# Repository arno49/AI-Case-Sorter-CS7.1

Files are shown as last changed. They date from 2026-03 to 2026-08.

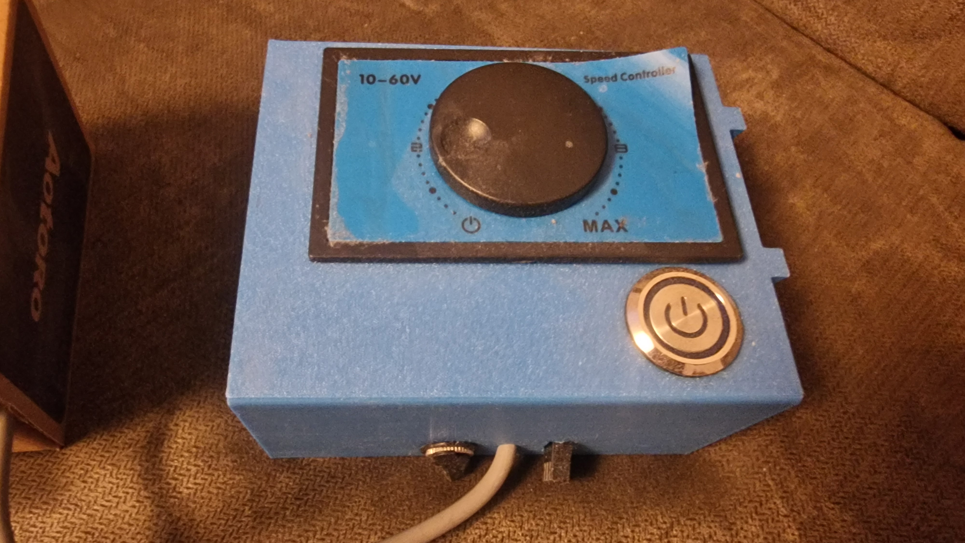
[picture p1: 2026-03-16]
CommunityContributions/Misc/SilverBullit/20260315_165633006.jpg

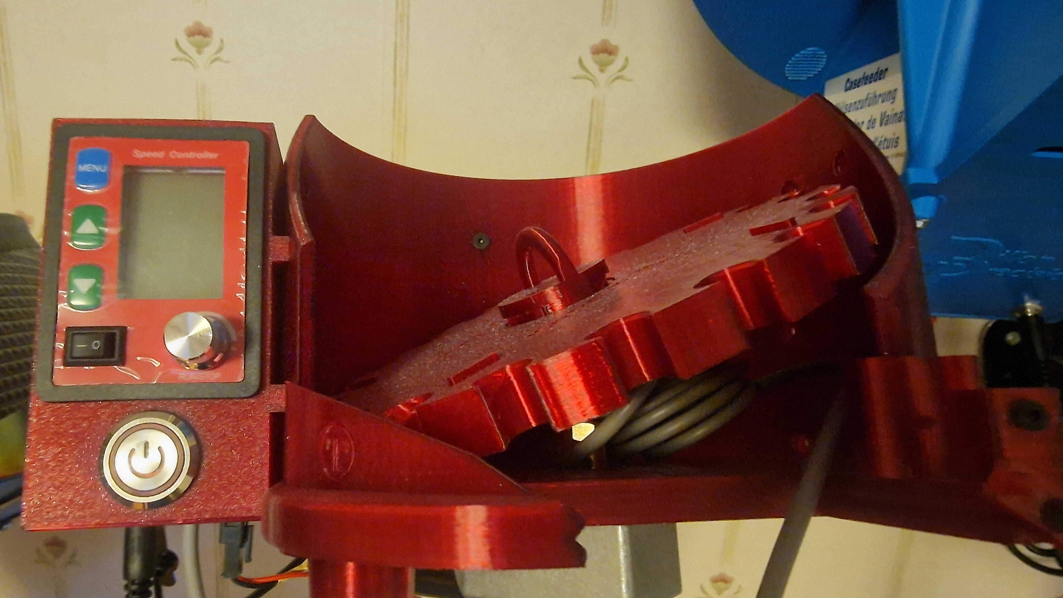
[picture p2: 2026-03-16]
CommunityContributions/Misc/SilverBullit/20260315_165454001.jpg

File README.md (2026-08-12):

# AI-Case-Sorter-CS7.1

This project builds a case sorter that uses machine vision and machine learning
to identify cartridge cases by headstamp. The repository contains the canonical
Arduino firmware, host protocol tooling, mechanical models, and the approved
architecture for a future Raspberry Pi 5 control appliance.

## Current software status

The canonical firmware is `7.1.260714.6`. Reset and the default `uno` build
remain protocol v1 for compatibility; `uno_v2` compiles opt-in v2 support while
also starting in v1.

| Environment | Current validated result |
| --- | --- |
| `uno` | 17,594 bytes flash / 899 bytes static SRAM |
| `uno_v2` | 26,290 bytes flash / 997 bytes static SRAM |
| `native` | 89 tests pass |
| `native_v2` | 49 tests pass |
| Python host package | 116 pytest tests pass |
| Python daemon/simulator | 318 pytest tests pass |
| `cs71-vision` package | 73 pytest tests pass |

The Python package under `host/` implements the v1/v2 client, typed protocol
models, CRC, fail-closed recovery, and the `cs71-protocol` compatibility CLI.
Physical bench, Linux DTR, HIL, and Windows-application qualification remain
required; software tests do not satisfy those gates. See
[ArduinoCode/README.md](ArduinoCode/README.md) for firmware details and
[host/README.md](host/README.md) for the host API and CLI.

## Software checks

From the repository root, run the firmware environments and the no-hardware host
package checks:

```sh
pio run -e uno && pio run -e uno_v2
pio test -e native && pio test -e native_v2
(cd host && python -m pip install ".[dev]" "build==1.2.2.post1" && python -m pytest && python -m build --wheel --sdist)
python -m unittest discover -s appliance/contracts/tests -v
(python -m pip install --require-hashes -r appliance/daemon/requirements-dev.txt && python -m pip install --no-build-isolation -e ./host -e ./appliance/daemon && cd appliance/daemon && ruff format --check . && ruff check . && mypy && pytest && python -m build --no-isolation --wheel --sdist)
(cd appliance/web && npm ci && npm run check:api && npm run lint && npm run check && npm test && npm run build)
python -m unittest discover -s appliance/ops/tests -v
```

These checks do not replace firmware serial parity, HIL, or Windows
qualification. `appliance/ops/tests/smoke-test.sh` is a further, functional
check that needs root on a real Linux host — it runs in CI (the
`appliance-ops` job) but is not part of this no-hardware list, and it does
not run on a Raspberry Pi either.

## Raspberry Pi 5 appliance documentation

The Raspberry Pi 5 control appliance executive summary is
[RASPBERRY_PI_WEB_ARCHITECTURE.md](RASPBERRY_PI_WEB_ARCHITECTURE.md). Its canonical
architecture, ADRs, delivery backlog, roadmap, and traceability are under
[docs/architecture/](docs/architecture/README.md). Firmware protocol behavior remains
in [ArduinoCode/PROTOCOL_V2.md](ArduinoCode/PROTOCOL_V2.md); the Python host-library
boundary is documented in [host/README.md](host/README.md).

The appliance architecture and executable private
[`cs71d` OpenAPI v1 contract](appliance/contracts/cs71d-v1.openapi.json) are
approved, and initial Python daemon/SvelteKit SSR workspaces now exist under
`appliance/`. The daemon workspace includes a deterministic, explicit-clock
protocol simulator for software-only development, and a single-owner serial
worker that confines all controller I/O to one dedicated thread and publishes
its session state. Opening a real serial port on Linux stays blocked by the
unqualified DTR gate. The web workspace now authenticates local operators: its
own `web.db`, Argon2id password hashing, opaque server-side sessions behind a
deny-by-default request hook, and one-time expiry-bound bootstrap provisioning
instead of a default password. Roles are enforced server-side against the
documented capability matrix, with every route declaring what it requires, and
state-changing requests must pass an origin and CSRF check and stay inside
documented rate, concurrency and size budgets. A socket-only daemon client backs
a dashboard that reads the machine snapshot and submits the software stop,
recording every attempt in the web audit. The dashboard also watches the machine
live: one reader of the daemon's event stream is fanned out to every open
browser, and a browser that may have missed something re-reads a snapshot rather
than presenting a state assembled from a gap. What the dashboard says is decided
in one tested module: acceptance is never worded as completion, a terminal the
controller did not confirm reads as an outcome that is not known, an unobserved
axis reads "not known" rather than "not homed", and the software stop — still
not an emergency stop — is the first control a keyboard reaches. Manual
connect, home and sort controls are offered capability-driven from the snapshot
the operator is looking at, each command form carrying that snapshot's
generation and a fresh idempotency key so a stale page is refused and a
resubmission cannot move the machine twice; the feed control stays disabled
with the daemon's reason for the unqualified firmware gate shown verbatim. The
operation history screen reads the durable record the daemon keeps, filtered
by exactly the state and type values the contract defines and paged forward
on the daemon's own cursor, describing every row with the same wording the
dashboard uses so an unsettled operation is never worded as a completion. A
machine whose state is not known renders visibly distinct from ordinary
attention rather than as a shade of it. Recovery is a dashboard control
gated to administrators, requiring an explicit confirmation checkbox this
workspace checks before anything reaches the daemon. A system view shows
firmware version, journal health inferred from recorded faults, storage
health explicitly reported as not available, and DTR-gate status read from
the daemon — presented as the project's own evidence-status legend defines
it and never as a pass. `appliance/ops/install.sh` installs both services as
separate least-privilege systemd units, a udev rule keyed to a specific
adapter's vendor ID, product ID and serial number together, and a Caddy site
that proxies only to loopback SvelteKit; its own smoke test proves the real
sandbox for real on a Linux CI host, though not yet on a Raspberry Pi.
`appliance/ops/backup.sh`, `restore.sh` and `upgrade.sh` take a
SQLite-consistent, checksummed backup of both databases and configuration on
a daily timer; restore verifies that checksum and each database's integrity
before installing anything and proves the daemon and web service actually
answer afterward; upgrade rebuilds from the checkout and rolls artifacts and
data back through restore on any failure before the web service is confirmed
healthy. The daemon's production profile now blocks new work the same way a
failed journal write already does when free disk space runs low or its own
backup has not succeeded recently enough. A third appliance service,
`cs71-vision` ([ADR-0013](docs/architecture/adr/0013-vision-classifier-service-and-hybrid-autonomy.md)),
now exists: a camera capture abstraction, packaged the same least-privilege
way, with a deterministic fixture backend for development/CI and a real
V4L2 backend for production that is not yet evidenced against real camera
hardware; and a self-labeling dataset that asks the daemon which slot each
completed sort actually reached and pairs that with the frame captured
nearest it, storing a labeled example only once the daemon has confirmed
the outcome — never guessed at from a frame alone.

The canonical firmware uses cooperative proximity settling: after the feed
sensor has been inactive longer than its debounce timeout, brass must keep the
sensor continuously active for the configured settle time. A sensor drop
cancels and restarts the full interval; brass already active at boot does not
settle until a qualifying absence occurs.

Sorter pre-homing jogs and the 40 ms `sorttest:` pacing interval are also
cooperative. Serial commands, including `stop`, remain responsive between
sorter steps and diagnostic moves. Runtime code uses no millisecond `delay()`;
only the microsecond delays that form and pace individual step pulses remain.

The `test:` and `sorttest:` diagnostics use the independent
`SORTER_SLOT_COUNT` setting (default 8), selecting slots from 0 through 7 by
default. It can be changed for the current session with the exact serial command
`slotcount:{count}`; see [ArduinoCode/README.md](ArduinoCode/README.md) for
limits and application compatibility details.

## Instructions
Most of the information you need to build this project is available in [Instructions.pdf](Instructions.pdf).

---------
## Parts List
The parts list for this project can be found here:
[Parts List](https://www.reloadingrecipes.com/HeadstampSorter/Partslist)

--------

# CS7.1 Video Build Series

The release video for this project is here:

Watch the video (https://youtu.be/s7dy0odA44U)

Follow along with me as I build the various components of this system. 

## Classifier
Build the Classifier (https://youtu.be/lhxDmvg5AVQ)

## Sorter
Build the Sorter (https://youtu.be/rP7bBV_uqF4)

## Camera Module
Build the Camera (https://youtu.be/iOc7inAcXpQ)

## Electronics
Build the Electronics (https://youtu.be/cS54LOCpNGc)

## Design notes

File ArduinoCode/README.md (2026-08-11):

# AI-Case-Sorter-CS7.1
This repo was created to isolate all the code and resources for the CS7.1 Version

## Release validation status

Firmware `7.1.260714.6` compiles for Arduino Uno with PlatformIO. The current
software baseline has 89 passing `native` tests, 49 passing `native_v2` tests,
and 100 passing Python host tests. CI builds both Uno variants and runs the
firmware and host suites. Physical bench validation is still required before
treating this firmware as a hardware release: motor direction, homing and
offsets, stop latency, AirDrop pulse timing, PWM output, sensor behavior, Linux
DTR behavior, and Windows application compatibility have not been exercised
from the development environment.

### V2-08 software evidence

| Build | Flash | Static SRAM | Gate |
| --- | ---: | ---: | --- |
| `uno` | 17,594 bytes | 899 bytes | 29,000 / 1,250 bytes |
| `uno_v2` | 26,290 bytes | 997 bytes | 29,000 / 1,250 bytes |

The matching native resource fixture is
`test/support/v2_08_resource_fixture.h`. V2-08H hardware status is
**NOT_EXECUTED**: no hardware stand was used, so physical completion timing,
motor behavior, and cancellation timing remain unverified.

## Build and test

The canonical sketch remains
`ArduinoCode/CS71_Arduino/CS71_Arduino.ino`. Open it in Arduino IDE, select
**Arduino Uno**, and use **Verify** or **Upload**.

PlatformIO provides an optional command-line workflow from the repository root:

```sh
pio run -e uno
pio test -e native
```

Run the complete firmware and host software checks from the repository root:

```sh
pio run -e uno && pio run -e uno_v2
pio test -e native && pio test -e native_v2
(cd host && python -m pip install ".[dev]" "build==1.2.2.post1" && python -m pytest && python -m build --wheel --sdist)
```

Run one native test suite with:

```sh
pio test -e native -f test_logic
pio test -e native -f test_command_parser
pio test -e native -f test_machine_state
pio test -e native -f test_runtime_timer
pio test -e native -f test_feed_completion
pio test -e native -f test_proximity_settler
pio test -e native -f test_step_sequence
pio test -e native -f test_crc16
pio test -e native_v2 -f test_protocol_v2_envelope
pio test -e native_v2 -f test_physical_request_tracker
```

## Serial command framing

For the normative engineering contract used to build host applications, see
[`PROTOCOL.md`](PROTOCOL.md).

The approved opt-in protocol v2 and legacy compatibility switcher are specified
in [`PROTOCOL_V2.md`](PROTOCOL_V2.md). Its dependency-ordered implementation and
rollout plan is in [`PROTOCOL_V2_PLAN.md`](PROTOCOL_V2_PLAN.md).

The firmware accepts commands at 9600 baud. Each command is terminated by
newline (`\n`); a single carriage return immediately before newline is ignored,
so CRLF is also accepted. Command payloads may contain up to 40 bytes.

If a payload exceeds 40 bytes, the complete line is discarded through its
newline and the firmware replies `error:command too long`. The next line starts
a fresh command. Runtime setting values must be complete integers within their
supported ranges. Boolean settings accept `true`/`false` (case-insensitive) or
`1`/`0`; malformed values return `error:invalid <setting>` without changing the
previous value.

`slotcount:{count}` sets the number of destinations used by both diagnostic
commands and replies `ok`. The value must be at least 1 and no greater than
`floor(32767 / (SortSteps * SORT_MICROSTEPS)) + 1`; invalid input replies
`error:invalid slotcount` and preserves the previous value. Changing
`sortsteps:` is also rejected when it would make the current diagnostic slot
count unsafe. Slot count does not limit ordinary numeric, `xf:`, or `sortto:`
commands, whose existing AVR-safe range is unchanged.

`SlotCount` is deliberately absent from `getconfig`: supported Windows
application versions have not been verified to tolerate an additional JSON
property. Set it manually in a 9600-baud serial terminal with, for example,
`slotcount:8`, or send that exact command from the application's advanced
configuration facility after its usual `sortsteps:` initialization. Runtime
settings reset at restart. To change the firmware default, edit
`SORTER_SLOT_COUNT` in the user configuration section.

Frames containing an embedded NUL byte are discarded with
`error:invalid command`.

## Serial command reference

| Command | Response and behavior |
| --- | --- |
| `{slot}` | Queues a destination and starts the pipelined feed/sort cycle; eventually emits `done`. |
| `xf:{slot}` | Same cycle while bypassing the feed sensor; eventually emits `done`. |
| `sortto:{slot}` | Acknowledges with `ok` and moves directly for diagnostics. |
| `homefeeder`, `homesorter` | Acknowledge with `ok` when recovery starts. |
| `stop` | Cancels active work, disables the shared driver, and emits `stopped`. |
| `test:{count}`, `sorttest:{count}` | Emit `testing started`, progress lines, and run the requested diagnostics. |
| `version` | Emits the firmware version alone. |
| `getconfig` | Emits one line of JSON containing the supported runtime settings. |
| `ping` | Emits the legacy response ` ok` with a leading space. |

Runtime setters acknowledge valid values with `ok` and use these exact names:
`feedspeed:`, `feedsteps:`, `feedhomingoffset:`, `sortspeed:`, `sortsteps:`,
`sorthomingoffset:`, `slotcount:`, `notificationdelay:`, `slotdropdelay:`,
`automotorstandbytimeout:`, `debounceTimeout:`, `debounceTime:`,
`airdropenabled:`, `airdroppredelay:`, `airdroppostdelay:`,
`airdropdsignalduration:`, and `cameraledlevel:`. Preserve the mixed-case
debounce names and the legacy extra `d` in `airdropdsignalduration:`.

Unknown nonnumeric commands retain the legacy `ok` response. Invalid setters
emit `error:invalid <setting>`; framing errors, busy state, unavailable position,
and feed overtravel use their documented `error:` responses.

## Stop and recovery

`stop` is a software control command, not a certified emergency stop or a
substitute for physically isolating motor power. A complete exact `stop` frame
is handled while feed, sort, or homing motion is active and replies exactly:

```text
stopped
```

It disables the shared motor driver, forces the feed-done output low, cancels
motion, homing, tests, completion notifications, and the pending command, and
marks both axis positions unknown. Serial input is checked on each cooperative
loop pass, including between pre-homing sorter jog steps and sorter diagnostic
moves.

The machine starts in `Recovering` mode and enters `Running` only after both
axes finish homing, including configured offsets. After `stop`, issue
`homefeeder` and `homesorter` (in either order); each replies `ok` when homing
starts. The motor driver is re-enabled for recovery. Once both axes are known,
the sorter queue is reset to zero and normal commands are accepted. Builds with
either homing sensor disabled mark that axis known deterministically when its
home operation is serviced.

The startup sorter pre-jog runs as one step per loop pass. Feeder and sorter
homing begin together only after that jog completes, preserving startup
ordering without blocking serial input. `homesorter` acknowledges immediately,
runs the same cooperative pre-jog, and then homes only the sorter. Stop and
feed faults cancel a pending jog so it cannot later start homing.

While stopped or recovering, `stop`, `version`, `getconfig`, `ping`, all runtime
configuration setters, `homefeeder`, and `homesorter` remain available. Numeric
feed/sort commands, `xf:`, `sortto:`, `test:`, and `sorttest:` reply:

```text
error:not homed
```

While execution is busy, one complete ordinary command can be held pending.
Any additional completed ordinary frame replies `error:busy`; it starts a new
frame and is never appended to the pending command. A pending command is not
dispatched until motion and homing are idle and any preceding feed-cycle
`done` notification has been emitted.

## Nonblocking feed completion

After feed homing completes, feed notification runs cooperatively without
`delay()`. With AirDrop enabled, firmware waits `AirDropPreDelay`, drives
`FEED_DONE_SIGNAL` high for `AirDropSignalTime`, drives it low, waits
`NotificationDelay`, and then emits `done`. Without AirDrop, it waits only
`NotificationDelay`. AirDrop mode and all three durations are snapshotted when
completion starts, so a queued runtime setter affects the next cycle.

Completion remains busy until `done` is emitted, preserving one-command pending
behavior. `stop`, feed overtravel, or leaving `Running` mode cancels the
completion, forces `FEED_DONE_SIGNAL` low, and suppresses stale `done` output.
`AirDropPostDelay` remains the independent slot/drop clearance gate.

## Cooperative sorter diagnostics

`sorttest:` uses a cooperative 40 ms `RuntimeTimer` gate before each random
sorter move. Both `test:` and `sorttest:` choose from the upper-exclusive range
`[0, slotCount)`. The independent default of 8 covers slots 0–7; this expands
the former `test:` default range of 0–5. Chute spacing and slot count must both
match the installed mechanics and are not derived from each other. The
return-to-zero move and pending-command blocking are unchanged. `stop` cancels
the pacing gate and test. Runtime firmware contains no `delay()` calls; only
`delayMicroseconds()` calls for step pulse width and motor speed remain.

## Proximity settling

After the feed sensor has remained inactive for longer than
`DebounceTimeout`, the next detected case must keep the sensor continuously
active for `DebouncePauseTime` before feeding can begin. This settling interval
is cooperative, so serial handling and `stop` remain responsive. If the sensor
drops inactive during settling, the timer is canceled and a full active
interval is required when the case returns. A case already active at boot does
not settle until a qualifying absence occurs.

`xf:` and builds with `FEEDSENSOR_ENABLED=false` bypass readiness without
clearing a pending settle requirement. Stop and feed-fault/recovery paths reset
active settling so stale expiry cannot start movement.

A feed-overtravel fault disables the motor driver and marks the feeder position
unknown. An already accepted pending command is processed afterward under the
normal recovery restrictions, so movement receives `error:not homed` while
diagnostics and homing remain available. Home the feeder successfully before
movement commands are accepted again. If sorter motion was active when the
fault occurred, it is cancelled and the sorter must also be homed.

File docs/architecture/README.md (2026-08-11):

# CS7.1 Raspberry Pi 5 Architecture

**Status:** Proposed implementation architecture; decisions listed below are accepted. This set is the canonical architecture for the Raspberry Pi 5 control appliance. It supersedes detailed design material in [RASPBERRY_PI_WEB_ARCHITECTURE.md](../../RASPBERRY_PI_WEB_ARCHITECTURE.md), which is now an executive summary. Firmware wire behavior remains canonical in [ArduinoCode/PROTOCOL_V2.md](../../ArduinoCode/PROTOCOL_V2.md); its delivery gates remain in [ArduinoCode/PROTOCOL_V2_PLAN.md](../../ArduinoCode/PROTOCOL_V2_PLAN.md).

## Document map

| Document | Primary audience | Canonical subject |
| --- | --- | --- |
| [vision-and-scope.md](vision-and-scope.md) | product, safety, delivery | outcome, scope, targets, assumptions and gates |
| [system-context.md](system-context.md) | all contributors | boundaries, containers, dependencies and failures |
| [runtime-and-domain.md](runtime-and-domain.md) | daemon and web engineers | state, scheduling, recovery and event semantics |
| [api-and-events.md](api-and-events.md) | daemon and BFF engineers | internal HTTP/JSON and SSE contract rules |
| [data-and-persistence.md](data-and-persistence.md) | service and operations engineers | database ownership and recovery |
| [security-and-safety.md](security-and-safety.md) | security, safety, operators | threats, access, invariants and safety boundary |
| [deployment-and-operations.md](deployment-and-operations.md) | release and operations engineers | Pi deployment and runbooks |
| [testing-and-quality.md](testing-and-quality.md) | QA and CI engineers | evidence, tests and gates |
| [roadmap.md](roadmap.md) | delivery leads | milestones and dependency order |
| [backlog.md](backlog.md) | implementers | PR-sized work and objective acceptance criteria |
| [traceability.md](traceability.md) | reviewers | requirements-to-evidence mapping |
| [adr/README.md](adr/README.md) | decision makers | accepted decision index and ADR process |

The executable daemon API source is
[`appliance/contracts/cs71d-v1.openapi.json`](../../appliance/contracts/cs71d-v1.openapi.json);
architecture prose explains its semantics but does not replace it.

## Status legend

| Label | Meaning |
| --- | --- |
| **Accepted** | A binding architectural decision for this appliance. |
| **Target** | A measurable desired level, not a measured result. |
| **Gate** | Work or evidence required before a stated use is allowed. |
| **NOT_EXECUTED** | A result deliberately not performed; it is not a pass. |
| **UNCERTAIN** | Hardware/session state cannot be trusted; dependent motion is blocked. |

## Principles

1. `cs71d` is the sole serial-device owner and calls `cs71_protocol`; the browser reaches only SvelteKit.
2. Safety is fail-closed: lack of trusted correlation, journal durability, or recovery verification is never success.
3. Daemon API versioning and IDs are separate from the Arduino protocol and its `request_id`.
4. Node/SvelteKit restart must not interrupt a serial operation already owned by `cs71d`.
5. A software stop is not an E-stop. Linux DTR behavior is NOT_EXECUTED until its dedicated hardware gate passes.
6. Simulator evidence proves simulator-supported behavior only and never closes a hardware gate.

## Decision and delivery indexes

The accepted decisions are [ADR-0001](adr/0001-two-process-modular-monolith.md) through [ADR-0012](adr/0012-versioned-operations-events-idempotency.md). Delivery work is dependency-ordered in [backlog.md](backlog.md); the milestone view is [roadmap.md](roadmap.md). The requirement-to-test route is [traceability.md](traceability.md).

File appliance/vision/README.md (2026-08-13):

# cs71-vision

The third appliance service (`docs/architecture/adr/0013-vision-classifier-service-and-hybrid-autonomy.md`):
camera capture and, in later PI-VISION tasks, classification. It never opens
the serial device and never bypasses `cs71d` — it only ever asks `cs71d` to
act, the same way `cs71-web` does today.

PI-VISION-001 shipped the camera abstraction and capture loop. PI-VISION-002
added the self-labeled dataset: `cs71-vision` reads `cs71d`'s own operation
history (never `machine.db` directly) to learn which slot a completed sort
actually reached, and pairs that with a frame it already captured.
PI-VISION-003 gives `cs71-vision` its first HTTP surface of its own — a
single read-only resource the web BFF queries for dataset review — so it now
talks to the web side, but only ever to answer that one read. PI-VISION-004
adds the training pipeline itself: a candidate classifier can now be trained
from the recorded dataset and stored as a new version. PI-VISION-005 gives
an operator a bounded way to trigger that training, activate a candidate and
roll back. PI-VISION-006 puts the active model to work, read-only: it
classifies the latest captured frame on its own background loop and shows
the operator a suggestion before they pick a slot — `cs71-vision` still
never issues a `cs71d` command itself, under any configuration; that is
PI-VISION-007/008's job, gated by an actor kind that does not exist yet.

## Self-labeled dataset (PI-VISION-002)

The whole point: build a labeled training set for free, from ordinary
operator-driven sorting, with zero extra effort from anyone.

- `cs71vision.daemon_client.DaemonClient` is a minimal, **read-only** HTTP
  client for `cs71d`'s private Unix-socket API — `GET /v1/operations` only,
  authenticated with its own service credential
  (`/etc/cs71-vision/service-token`, a third copy of the same shared secret
  `cs71d`/`cs71-web` already use). It reads which slot a `SUCCEEDED` sort
  operation reached from `terminal_fields.slot` — the *only* place that
  value is exposed; `cs71d`'s operation records carry no other durable,
  externally readable trace of "which slot" (this PR is what taught the
  daemon's own contract to expose it, additively, since nothing needed it
  before).
- `cs71vision.correlator.FrameBuffer` keeps the last 64 captured frames;
  `Correlator.poll_once()` asks `cs71d` for newly succeeded sorts, finds the
  frame captured at-or-before each one's `created_at`, and hands the pair to
  the dataset store. A success with no matching frame is discarded, not
  guessed at — this is deliberately conservative rather than approximate.
- `cs71vision.dataset.DatasetStore` owns `vision.db` exclusively, the same
  separate-ownership rule `machine.db`/`web.db` already follow: forward-only
  checksummed migrations, WAL mode, owner-only file mode, the same shape as
  `cs71d.journal.Journal`. `operation_id` is the primary key, so polling the
  same `cs71d` operation twice is a no-op, never a duplicate.
- `cs71vision.runtime.CorrelationLoop` polls on its own thread and its own
  interval (2s by default), independent of the capture interval — it
  reconciles against `cs71d`'s durable record, it does not drive capture.

Wiring is additive and optional: a config with no `daemon_service_token_path`
runs exactly like PI-VISION-001's plain capture-only mode. Set it, and
`cs71-vision` starts correlating against `cs71d` automatically.

## Dataset api (PI-VISION-003)

Lets an operator see training readiness before training is offered, not
after (ADR-0013). `cs71vision.api.VisionApiServer` (renamed from
`DatasetApiServer` in PI-VISION-005, once it grew routes beyond the
dataset) serves `GET /v1/dataset` on its own Unix domain socket — mirroring
`cs71d.api`'s shape (bearer auth against the same shared service
credential, stale-socket reclaim on start, `AF_UNIX`-only) at a fraction of
its surface: no event stream, and (still, even after PI-VISION-005) no
concept of an authenticated *operator* — see below. The response is
per-class counts against the configured floor:

```json
{
  "api_version": "v1",
  "minimum_examples_per_class": 40,
  "classes": [
    { "slot": 3, "count": 52, "eligible": true },
    { "slot": 5, "count": 12, "eligible": false }
  ],
  "training_ready": true
}
```

A "class" is the slot the operator sorted into — the same self-labeling
ADR-0013 describes, so this introduces no second labeling concept. The floor
is `minimum_examples_per_class` in `cs71vision.config.VisionConfig` (default
40, configurable per installation); a class below it is `eligible: false`,
never merely absent. `training_ready` is true once at least one class clears
the floor.

Same gate as correlation: `cs71vision.runtime.build_api_server` returns
`None` when `daemon_service_token_path` is unset — no credential to
authenticate a caller against, and nothing in the dataset ever gets
populated either, so capture-only mode exposes no api. It opens its own
`DatasetStore` connection, independent of the correlation loop's — safe
under the WAL mode `DatasetStore.open` already enforces, and it keeps this
server's lifecycle free of any dependency on whether correlation happens to
be running.

The web BFF's side is `appliance/web/src/lib/server/vision/client.ts` — a
small hand-typed client, not a second generated OpenAPI contract: one
resource does not justify that weight yet (see PI-VISION-003's backlog
entry for the full reasoning, and revisit if PI-VISION-004/005 grow this
surface). It reuses the daemon module's own Unix-socket transport and
credential reader, both already generic infrastructure, and reads through
`cs71-web`'s existing copy of the shared service credential — the same
secret `cs71-web` already presents to `cs71d`, no new credential to
provision. The operator-facing page is `/dataset`
(`appliance/web/src/routes/dataset/`), gated by the same `machine.read`
capability `/system` uses.

## Training pipeline (PI-VISION-004)

Trains one candidate classifier from the examples `vision.db` already holds,
and stores it as a new version - nothing more yet: no operator-facing
trigger, no activation, no live suggestion. Those are PI-VISION-005/006.

- `cs71vision.training.extract_features` turns a captured frame into a
  fixed-length, deterministic feature vector: decode to grayscale, resize to
  32x32 regardless of the frame's own resolution, normalize to `[0, 1]`. No
  learned embedding and no claim that this is the best feature set - it is a
  bootstrap one, free to be replaced later without touching anything
  downstream of it.
- `cs71vision.training.train_candidate` groups examples by slot, excludes
  any class below `minimum_examples_per_class` **outright** (it never
  reaches feature extraction, not merely a UI flag), and refuses to train at
  all when fewer than two classes clear the floor. Each included class is
  deterministically split into a training pool and a held-out subset (a
  `random.Random(seed)` local to the call - never wall-clock or global
  random state); held-out accuracy is computed strictly from examples the
  classifier never trained on.
- The classifier is `scikit-learn`'s `RandomForestClassifier`
  (BSD-3-Clause) - the same well-tested-over-hand-rolled, permissive-license
  reasoning that put OpenCV over a hand-rolled V4L2 implementation in
  PI-VISION-001, sized for a background job training on tens to a few
  hundred examples per class on a Pi 5 CPU, not a deep-learning framework
  sized for a workload this is not. The fitted classifier is serialized with
  `pickle`; no new on-disk model-file format was introduced.
- Storage extends `vision.db` itself (schema version 2, a `models` table),
  not a new file or directory: `DatasetStore.record_candidate` is a plain
  `INSERT` against an `AUTOINCREMENT` primary key, so a previously recorded
  candidate is never overwritten - there is no `UPDATE`/`DELETE` path onto
  that table anywhere in this codebase. `DatasetStore.candidates()` reads
  every recorded candidate's metadata (no model blobs);
  `candidate_model(version)` reads one blob by version. This needed zero
  `appliance/ops/` changes: `vision.db` is already backed up and restored
  wholesale, table-agnostic.
- `cs71vision.runtime.TrainingJob` is a trigger, not a schedule:
  `trigger()` starts one run on its own thread and returns immediately; a
  second `trigger()` while one is in flight returns `False` rather than
  stacking a second pass behind the first. `build_training_job` shares
  `build_correlation_loop`'s/`build_api_server`'s own gate on
  `daemon_service_token_path`: without a token, correlation never runs, so
  `vision.db` never receives an example in the first place and there is
  structurally nothing to ever train from.

What remains genuinely hardware-gated: `RandomForestClassifier`'s wall-clock
training time on real captured frames, at real dataset sizes, on a real
Pi 5 CPU is unmeasured here - every test runs against small, fast synthetic
images on ordinary CI hardware. The same class of gap `V4L2Camera`'s
real-hardware behavior and the DTR gate already are for this workspace.

## Training, activation and rollback api (PI-VISION-005)

`VisionApiServer` gained four more routes, all on the socket above, once
there was an operator-facing surface (`vision.train`, below) to gate them
with:

- `GET /v1/models` — every recorded candidate's metadata, the active
  version (`null` before anything has ever been activated), and
  `can_roll_back` — computed from the same activation history
  `POST /v1/rollback` itself checks, not left for a caller to approximate
  from candidate count (a model trained several times but only ever
  activated once has nothing to roll back to, despite several candidates
  existing).
- `POST /v1/train` — calls `TrainingJob.trigger()`, PI-VISION-004's own
  trigger-not-scheduler design; `{"started": false}` means a run was
  already in flight, not an error.
- `POST /v1/models/{version}/activate` — records a new activation event for
  that version. `404` if this store never recorded a candidate at that
  version.
- `POST /v1/rollback` — activates whatever version was active immediately
  before the current one. `400 VALIDATION_FAILED` if fewer than two
  activations have ever happened.

None of the four carry an actor, an idempotency key or a generation:
`cs71-vision` has no concept of "which operator" and never will for this
surface - attribution is entirely `cs71-web`'s job (`recordAudit`), the same
way `cs71d` never learns a browser identity either, only a service identity.

**Storage: an append-only `activations` table, not a mutable "current
model" pointer.** Schema version 3 adds `activations` (`version INTEGER NOT
NULL REFERENCES models(version)`), the same append-only discipline
`web_audit` already uses on the web side: `DatasetStore.activate(version)`
is a plain `INSERT`, never an `UPDATE`. "Roll back" is not a distinct
storage operation - it is a caller activating whatever version
`DatasetStore.activations()`'s second-to-last row names.
`DatasetStore.active_version()` is simply the latest row's version. This
means "the previously active version is retained, never overwritten in
place" (this task's own backlog requirement) holds structurally, the exact
way it already does for the `models` table itself.

Constructing a `VisionApiServer` now also constructs a `TrainingJob` (its
own independent `DatasetStore` connection, the same reasoning PI-VISION-003
already established for why an independent connection is safe under WAL
mode) and closes it in `close()`. `api.py` describes what it needs from that
job as a small `Trainable` `Protocol` (`trigger()`, `close()`) rather than
importing `TrainingJob` concretely - `runtime.py` builds a `VisionApiServer`
(`build_api_server`), so a concrete import the other way would be circular.

**Web side:** `appliance/web/src/lib/server/vision/client.ts` gained
`models()`/`train()`/`activate()`/`rollback()` on the same hand-typed
client PI-VISION-003 chose, reusing the same transport/credential
infrastructure. `vision/errors.ts` grew a real per-code error mapping here
- PI-VISION-003's dataset read had nothing worth distinguishing (every
failure meant "the numbers could not be shown"), but these are real actions
with distinct, actionable refusal reasons, the same shape `daemon/errors.ts`
already uses. `/dataset` (`appliance/web/src/routes/dataset/`) gained a
models section: every candidate's accuracy shown in a table next to the
active model's own, directly above that candidate's own activate control -
the page structure itself is what satisfies "activation is refused unless
the operator has been shown the candidate's accuracy alongside the
currently active model's" (ADR-0013), not a separate confirmation step.
`vision.train` is a new RBAC capability, granted at the `operator` row
(`security-and-safety.md`) - a deliberate departure from this project's own
pattern of reserving impactful actions to `administrator`, since none of
these actions touch machine motion or `cs71d` at all.

## Read-only classification suggestion (PI-VISION-006)

Puts the active model to work, without ever letting it act: "read-only" is
architectural here, not a UI choice - nothing in this feature's request path
ever calls `cs71vision.daemon_client.DaemonClient` at all, so there is no
code path, under any configuration, that could turn a suggestion into a
`cs71d` command.

- `cs71vision.classifier.classify_frame(model_blob, frame_png)` is the
  primitive: unpickle the stored model (the same trust boundary `training.py`
  already accepts for `pickle` - this process's own output, never anything
  else), run PI-VISION-004's own `extract_features`, and read
  `predict_proba` for the top class and its confidence.
- `cs71vision.classifier.FrameSuggester` is the one thing
  `cs71vision.runtime.SuggestionLoop` calls each tick, the same
  separation-of-concerns `correlator.Correlator`/`runtime.CorrelationLoop`
  already keep: no active model yet, or nothing captured yet, both mean
  "nothing to suggest" - not an error. `build_suggestion_loop` shares every
  other `vision.db`-backed component's own gate: without a token,
  correlation never runs, so no example is ever recorded and no model is
  ever trained, meaning there is structurally never an active model to
  suggest from.
- Storage is two more append-only tables (schema version 4): `suggestions`
  (one row per classification) and `suggestion_outcomes`
  (`suggestion_id`/`operation_id` both `UNIQUE`, so a suggestion is matched
  at most once). `correlator.Correlator` gained exactly one more step in its
  existing per-success loop: after recording a new example, it also asks
  `DatasetStore.unmatched_suggestion_at_or_before(created_at)` - the same
  "newest evidence at or before this moment, `None` means discard, never
  guess" contract `FrameBuffer.closest_at_or_before` already uses for
  frames - and records whether it matched. This is the same correlation
  pass PI-VISION-002 already runs, on the same cadence; nothing new polls
  `cs71d`.
- `VisionApiServer` gained two pure-read routes: `GET /v1/suggestion` (the
  most recently recorded suggestion, or `null`) and
  `GET /v1/suggestion-accuracy` (`total`/`correct`/`accuracy`, the last
  `null` rather than a fabricated zero before anything is matched). Neither
  route classifies on demand or writes anything - `SuggestionLoop` is the
  only writer.

**Web side:** the dashboard (`/`) shows the current suggestion
informationally, directly above the existing manual sort form - the same
page an operator already uses to pick a slot, not a new one. A
`cs71-vision` outage here is caught and logged, never surfaced as a page
error: sorting does not depend on `cs71-vision` (ADR-0013), and the
dashboard's own daemon-read failure handling stays untouched by it.
`/dataset` shows live suggestion accuracy as a third, visibly distinct
figure next to the per-candidate held-out accuracy PI-VISION-005 already
renders - different evidence, since one measures a held-out split of
training data and the other measures real operator decisions after
activation.

What remains genuinely hardware-gated: the same class of gap PI-VISION-001/004
already carry. Nothing here runs against a real camera or a model trained on
real frames; every suggestion in this test suite classifies small, fast
synthetic solid-color images on ordinary CI hardware.

## Primer-presence axis (PI-VISION-010)

A permanently separate signal from `slot`/`confidence`, matching ADR-0013's
`machine`-actor design intent and SAF-09: primer presence must always
require a person to confirm, regardless of manufacturer-class confidence or
any future autonomy configuration (PI-VISION-008), and no configuration
surface may ever disable that.

- `cs71vision.primer.requires_operator_confirmation(primer_present)` is the
  single, uncircumventable answer: `True` unless `primer_present` is exactly
  `False`. It takes no configuration parameter - there is no argument that
  could ever be passed to bypass it, the same structural non-grant
  `appliance/web/src/lib/server/auth/capabilities.ts` already uses for
  `protocol.direct` (declared, never granted to any role).
- `classifier.Suggestion` and `dataset.SuggestionRecord` both gained a
  `primer_present: bool | None` field (schema version 5, one additive
  `ALTER TABLE`, not a mutation of an existing column). It is always `None`
  today: no trained primer detector exists anywhere in this codebase, since
  nothing has ever seen a labeled primer example - so nothing may ever
  fabricate a confident `False` reading. This mirrors SAF-07/SAF-08's own
  posture: this axis is not "closed" by software evidence.
- `GET /v1/suggestion` reports both `primer_present` and
  `requires_confirmation` (computed server-side from the same function, so
  no caller reimplements the safety logic for itself).

**Web side:** the dashboard shows an explicit primer confirmation notice
next to the class suggestion whenever `requires_confirmation` is true -
today, always, since no trained primer detector exists yet. This is
informational, the same as the suggestion itself: it does not itself block
a manual sort - what it actually delivers is the uncircumventable primitive
`cs71vision.autonomy.may_autonomously_sort` (PI-VISION-008) consults before
it may ever attempt one.

## Confidence-gated autonomous sort (PI-VISION-008)

The one place `cs71-vision` may ever issue a `cs71d` command: a `sort`,
submitted as the `machine` actor kind (PI-VISION-007), and only when a
suggestion clears two independent gates in a fixed order that cannot be
reordered away.

- `cs71vision.autonomy.may_autonomously_sort(suggestion, thresholds)` checks
  the primer axis first and unconditionally
  (`primer.requires_operator_confirmation`, PI-VISION-010/SAF-09) - no
  per-class threshold, however high, ever overrides it - then a per-class
  manufacturer-classification confidence threshold. A class absent from
  `thresholds` can never autonomously sort: conservative by omission, not a
  low default number (ADR-0013: "starting conservative... mostly manual").
- `cs71vision.autonomy.Autonomist` is the one thing `runtime.AutonomyLoop`
  calls each tick - kept as its own loop, not a step bolted onto
  `SuggestionLoop`'s own tick, so "never issues a `cs71d` command, under any
  configuration" stays true of `SuggestionLoop` by construction. It never
  submits twice for the same suggestion
  (`DatasetStore.autonomous_attempt_exists`), and a `cs71d` rejection
  (stale generation, an unreachable socket) is logged and left for the next
  tick to reconsider against a then-current suggestion.
- `DaemonClient.submit_sort` is the only place in this codebase that may
  ever present the `machine` service credential - a second, distinct token
  from the ordinary shared one, refused outright when unconfigured. It
  reads a fresh `current_generation()` immediately before every attempt and
  submits with a deterministic idempotency key
  (`autonomous-sort-<suggestion_id>`), so even a duplicate tick collapses
  into the same operation at `cs71d`, never a second sort of the same case.
- `build_autonomy_loop` gates on *both* `daemon_service_token_path` and
  `machine_service_token_path` being configured - distinct from
  `build_suggestion_loop`'s own gate, since a machine credential can be
  entirely unset while ordinary suggestion/correlation keeps running (the
  same "provisioned does not mean active" posture `cs71d`'s own
  `machine_service_token_path` uses, PI-VISION-007).

**There is no ground truth for an autonomous sort to compare itself
against** - unlike a manual sort, there is no operator confirmation step to
diff the suggestion against. So the false-autonomous-sort rate ADR-0013
requires be measured and recorded before a class's threshold may be
lowered is never inferred, only recorded from what a person reports after
actually checking: `DatasetStore.record_autonomous_review` is an
append-only human verdict on one `autonomous_attempts` row, and
`autonomous_accuracy_by_class` reports the reviewed false rate per class -
a class with attempts but zero reviews yet is absent, never reported as 0%
false, so "unreviewed" and "reviewed clean" can never look the same.
`GET /v1/autonomy` exposes configured thresholds, the reviewed accuracy and
the pending-review queue together; `POST /v1/autonomous-reviews` records
one verdict.

**Provisioning enables the mechanism, not the policy.** The machine
credential is always provisioned to both `cs71d` and `cs71-vision`
(PI-VISION-007's `write_machine_service_token`), and
`production.example.toml` now points both services at it - but
`autonomy_thresholds` stays empty by default, which structurally means no
class may ever be sorted autonomously until an installation explicitly
configures one, per class, after reviewing that class's own recorded
evidence.

## Configurable routing profiles (PI-VISION-009)

Before this task, "manufacturer class" and "physical chute" were the same
integer everywhere in this codebase - `classify_frame`'s own output,
`Suggestion.slot`, `example.slot`, all of it - with zero indirection,
because Phase 0's dataset recorded exactly what the operator's own manual
sort actually reached. Several dozen manufacturer classes do not fit 8-10
physical chutes, and different runs want different mappings (ADR-0013);
this module is the missing layer between a class label and the chute a
suggestion or an autonomous sort actually targets.

- `cs71vision.routing.RoutingSession` owns the one active run, if any -
  shared between the api server (`start`/`stop`/`snapshot`, on request
  threads) and the suggestion loop (`route`, on its own thread), the same
  "one shared, lock-guarded object" shape `DatasetStore` already uses.
  `route(class_id)` is the identity function whenever no run is active, so
  nothing about existing behaviour changes unless an operator explicitly
  starts one.
- Three profile shapes, matching ADR-0013 exactly: `FixedMapProfile` (an
  explicit class-to-chute map plus one overflow chute for everything else),
  `DynamicProfile` (the first N distinct classes seen in this run claim a
  chute, in order, from N chutes named up front), and `TwoPassProfile` (the
  same shape as fixed, plus an optional `source_group` naming which prior
  pass's output chute this run refines - for display/audit only; this
  software does not and cannot verify that a second pass's physical input
  really came from that chute).
- `FrameSuggester` routes the classifier's raw output before it is ever
  stored or suggested (`classifier.Router`, PI-VISION-009's own addition to
  PI-VISION-006's suggester). Because the routed value becomes
  `suggested_slot`, live suggestion accuracy (PI-VISION-006) and autonomous
  sort (PI-VISION-008) both automatically operate in routed space with zero
  changes to either - an operator's actual sort is still compared to what
  was suggested, now correctly comparing chute to chute.
- `GET /v1/routing` (state and live legend), `POST /v1/routing/start`
  (replaces any previous run entirely - never merges), `POST /v1/routing/stop`
  (idempotent: stopping with no active run is not an error).

**Web side:** `/routing` lets an operator start any of the three profile
shapes and see the live chute<->class legend and, per ADR-0013's "the
active profile is visible throughout the run", the dashboard shows a
one-line notice whenever a run is active, linking to the details. Starting
or stopping a run is gated on `machine.operate`, not `vision.train`: it
shapes where a live sort actually lands, the same operational weight as
connect/home/sort/feed, not a model-quality decision.

## Camera

`cs71vision.camera.Camera` is a two-method protocol: `read()` returns a
PNG-encoded `Frame`, `close()` releases the source. Two implementations:

- `FixtureCamera` — deterministic, dependency-free, the same evidence role
  `appliance/daemon/src/cs71d/simulator` plays for the serial protocol.
  Every frame is a solid-color image whose value advances with an internal
  counter, never wall-clock time or randomness. This is what this
  workspace's own tests and CI actually exercise.
- `V4L2Camera` — a real camera, opened through OpenCV's V4L2 backend
  (`cv2.VideoCapture(path, cv2.CAP_V4L2)`), not a hand-rolled ioctl
  implementation. That trade-off is deliberate: reconstructing the V4L2
  mmap-streaming protocol's exact kernel-ABI struct layouts from memory,
  with no real V4L2 device anywhere in this development or CI environment
  to catch a wrong field offset against, is a correctness risk this
  workspace should not carry. Every small "V4L2 Python bindings" package on
  PyPI that exists to avoid writing that protocol by hand is itself
  GPL-licensed (a direct transcription of the GPL `linux/videodev2.h`
  kernel header), which does not fit this workspace's MIT license. OpenCV
  is Apache-2.0 (the `opencv-python-headless` packaging itself is MIT),
  battle-tested against exactly this class of UVC/V4L2 webcam — the camera
  hardware already specified in `3DModels/Classifier/CameraV2` is a plain
  USB VGA UVC module — and removes both the correctness risk and the
  licensing question in one move.

`V4L2Camera` is unit-tested only against its own refusal path (a device it
cannot open). Its real-hardware behavior is not evidenced anywhere in this
repository yet — the same class of gap the Linux DTR gate already is for
`cs71d`: real camera evidence is PI-HIL/hardware-evidence territory, not
something a fixture can stand in for.

## Configuration

`cs71vision.config` mirrors `cs71d.config` deliberately: three profiles
(`development`/`test`/`production`), a `fixture`/`v4l2` backend choice, and
a production profile that fixes every path (`PRODUCTION_DEVICE_PATH =
"/dev/cs71vision"`, the udev-created stable symlink for the approved camera
module — see `appliance/ops/udev/98-cs71-vision.rules`) so there is nothing
left to misconfigure. Development defaults to the fixture backend; nothing
here ever opens a real device unless a profile explicitly says to.

## Capture loop

`cs71vision.runtime.CaptureLoop` polls one `Camera` on a fixed interval, on
its own thread, and hands each frame to a `Sink` — a plain callable. A
camera read failure or a sink that raises is logged and the loop keeps
going; nothing here ever crashes the service over one bad frame. `cli.py`'s
sink both logs frame metadata and adds the frame to the `FrameBuffer` the
correlation loop reads from.

## Running it

```sh
cs71vision --check-config                      # validate the development defaults
cs71vision --check-config /etc/cs71/cs71vision.toml
cs71vision --serve                              # capture against the fixture backend
```

## Packaging

`appliance/ops/install.sh` installs `cs71-vision.service` alongside
`cs71d.service`/`cs71-web.service`, with the same least-privilege sandbox
pattern: its own system user, no access to the serial device or either
existing database. Camera hardware identity
(`--camera-vendor-id`/`--camera-product-id`) is optional at install time,
the same way the sorter's own adapter identity is required — if omitted,
`cs71-vision` is installed and enabled but has no matched device until an
operator supplies that hardware evidence.

`cs71-vision.service`'s *effective* `Group=` is `cs71-api` — the same shape
`cs71d.service` itself uses, not a `SupplementaryGroups=` grant — which does
two jobs with one directive: it lets `cs71-vision` reach `cs71d`'s socket as
a client, and it makes `cs71-vision`'s own new dataset-api socket
(PI-VISION-003, above) come out `cs71-vision:cs71-api` 0660, so `cs71-web`
can reach it through the same supplementary grant it already carries for
`cs71d`'s socket — no new grant needed on that side. Real OS-level group
membership is still granted separately in `install.sh`, for anything that
reaches this identity a different way (`su`, `runuser`) — see
`appliance/ops/README.md`. Its own `vision.db` lives under
`StateDirectory=cs71-vision` (`/var/lib/cs71-vision`), included in
`backup.sh`'s manifest and `restore.sh`'s restore path whenever it exists,
the same way `machine.db`/`web.db` already are — optionally, since an
appliance upgraded from a pre-PI-VISION install may not have one yet. The
dataset-api socket lives under `RuntimeDirectory=cs71-vision`
(`/run/cs71-vision`), recreated fresh on every start the same way
`cs71d.service`'s own `RuntimeDirectory=` is.

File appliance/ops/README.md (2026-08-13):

# Appliance packaging and lifecycle: systemd, udev, Caddy, backup/upgrade/restore

What `install.sh` builds on a Raspberry Pi (or any Debian-family Linux host,
for the smoke test): two least-privilege systemd services, a udev rule that
gives one of them exclusive access to one specific USB adapter, and a Caddy
site that fronts the other on the LAN. This mirrors
[deployment-and-operations.md](../../docs/architecture/deployment-and-operations.md)
and [ADR-0009](../../docs/architecture/adr/0009-native-systemd-udev-caddy.md);
where this document and that one differ on a detail, this one is the one the
installer actually does. `backup.sh`, `restore.sh` and `upgrade.sh` (PI-OPS-002)
are the maintenance half of the same document's "Install, upgrade and rollback"
and "Backups, observability and runbooks" sections.

## Layout

```text
/opt/cs71/web/                 SvelteKit source + a fresh npm ci/build, pruned to dependencies
/opt/cs71/daemon/venv/         a dedicated Python venv with cs71_protocol + cs71d installed into it
/opt/cs71/vision/venv/         a dedicated Python venv with cs71vision installed into it
/opt/cs71/ops/                 backup.sh's own installed copy, plus release-info.json (see below)
/etc/cs71/cs71d.toml           daemon config — world-readable, nothing secret in it
/etc/cs71/cs71vision.toml      vision config — world-readable, nothing secret in it
/etc/cs71/web.env              web PORT/HOST/ORIGIN — world-readable, nothing secret in it
/etc/cs71d/service-token       the daemon's own copy of the shared credential, cs71d:cs71d 0600
/etc/cs71-web/service-token    the web's own copy of the same credential, cs71-web:cs71-web 0600
/etc/cs71-vision/service-token the vision service's own copy of the same credential, cs71-vision:cs71-vision 0600
/var/lib/cs71d/machine.db      daemon-owned SQLite, cs71d:cs71d 0700 directory, 0600 file
/var/lib/cs71d/backup-status.json  the daemon's own BackupFreshnessMonitor reads this, cs71d:cs71d 0600
/var/lib/cs71-web/web.db       web-owned SQLite, cs71-web:cs71-web 0700 directory, 0600 file
/var/lib/cs71-vision/vision.db the self-labeled dataset (PI-VISION-002), cs71-vision:cs71-api 0700 directory, 0600 file
/var/lib/cs71-backups/<stamp>/ one backup.sh snapshot: all three databases, config and a manifest, root:root 0700
/run/cs71/cs71d.sock           systemd RuntimeDirectory=; recreated on every start, not persisted
/run/cs71-vision/cs71vision.sock  cs71-vision's own read-only dataset api (PI-VISION-003); systemd RuntimeDirectory=, recreated on every start, not persisted
```

**Three service-token files, not one.** `cs71d`, `cs71-web` and
`cs71-vision` are separate, mutually distrusting identities that happen to
need to agree on one shared secret: the daemon reads its own copy to know
what to accept (`cs71d.device`'s `service_token_path`), the web and vision
services each read their own copy to know what to present
(`CS71_WEB_SERVICE_TOKEN_PATH`, `cs71vision.config`'s
`daemon_service_token_path`). `deployment-and-operations.md`'s layout table
only shows the web's copy; this is the place that says there are three.

**A fourth, distinct credential pair for the machine actor kind**
(PI-VISION-007, ADR-0013) - `/etc/cs71d/machine-service-token` and
`/etc/cs71-vision/machine-service-token`, written by
`write_machine_service_token` (`lib/common.sh`), unconditionally, the same
way `write_service_tokens` always runs. This is a genuinely *different*
secret from the shared one above, not a fourth copy of it: `cs71-web` never
receives this file at all, since it has no legitimate reason to ever act as
the machine actor kind, and the daemon checks the actual credential
presented against the actual role claimed (see `appliance/daemon/README.md`'s
own "The machine actor kind" section) rather than trusting a request body's
say-so. The file is always provisioned. `cs71d.toml`'s
`machine_service_token_path` and `cs71vision.toml`'s own copy are both set
in `production.example.toml` as of PI-VISION-008 - the *mechanism* is
enabled - but that is not the same thing as the *policy* being active:
`cs71vision.toml`'s `autonomy_thresholds` stays empty by default, which
structurally means no class may ever be sorted autonomously
(`cs71vision.autonomy.may_autonomously_sort`) until an installation
explicitly configures one, and even then the primer-presence axis
(PI-VISION-010) can still block it regardless.

**`/etc/cs71/cs71d.toml`, `/etc/cs71/cs71vision.toml` and `/etc/cs71/web.env`
are root-owned and world-readable**, deliberately. Every value in them is
already fixed by the production profile (`config.py`/`config.ts` refuse
anything else) or is not secret in the first place (a LAN hostname, a port
number). The credential lives in the three files above instead, each mode
0600 and readable only by matching UID — not by group membership, so it
does not depend on which supplementary groups a service ends up with.

## Users and groups

| Identity | Owns | Access to the serial device | Access to the socket(s) |
| --- | --- | --- | --- |
| `cs71d` (user) | `/var/lib/cs71d`, `/etc/cs71d/service-token` | Yes — the only one | Creates `cs71d`'s |
| `cs71-web` (user) | `/var/lib/cs71-web`, `/etc/cs71-web/service-token` | No | Reaches `cs71d`'s and `cs71-vision`'s via the `cs71-api` group |
| `cs71-vision` (user) | `/var/lib/cs71-vision`, `/etc/cs71-vision/service-token`, `/dev/cs71vision` | No | Creates its own (PI-VISION-003) and reaches `cs71d`'s, both via the `cs71-api` group |
| `cs71-api` (group) | nothing | — | `cs71d.service` and `cs71-vision.service` each run with this as their *effective* group, so the socket each creates comes out `<owner>:cs71-api` 0660; `cs71-web.service` carries it as a supplementary group to reach both |

`cs71d.service` sets `Group=cs71-api` (not its own `cs71d` group) specifically
so the socket comes out group-owned `cs71-api`; everything else the daemon
process creates (`machine.db`) is separately protected by its own 0600 file
mode (`journal.py` sets this explicitly), so it does not depend on which
group owns it.

## Systemd units

`systemd/cs71d.service` and `systemd/cs71-web.service` share one design:
`NoNewPrivileges=yes`, `ProtectSystem=strict`, `ProtectHome=yes`, an empty
`CapabilityBoundingSet=`, and `RestrictAddressFamilies=` narrowed to exactly
what each needs — `AF_UNIX` only for the daemon (it has no code path that
ever opens an internet socket; `appliance/daemon/tests/test_api.py` asserts
that statically, and `tests/smoke-test.sh` proves the sandbox itself refuses
one at run time), `AF_UNIX AF_INET AF_INET6` for the web service (loopback
HTTP plus the daemon socket). Only `cs71d.service` declares
`DeviceAllow=/dev/cs71 rw`; the web unit has no device access at all.

`cs71d.service` only starts once the real adapter is present:
`BindsTo=dev-cs71.device` plus `ConditionPathExists=/dev/cs71` (the device
unit systemd auto-generates from the udev-tagged symlink below). There is no
way to functionally exercise that specific gate without the real USB
adapter, which is exactly why it is gated — `tests/smoke-test.sh` runs the
same sandbox directives against a derived unit with that gate removed and a
stub device file instead, on the simulator backend, so the rest of the
configuration is provably real without needing the hardware this backlog
item explicitly does not have (PI-OPS-001: "Hardware required: Pi required;
controller optional" — the controller is the part still missing).

`systemd/caddy-cs71.conf` is a drop-in for the *distribution's own*
`caddy.service`, not a replacement unit — Caddy already ships its own
hardened unit; this only adds `After=`/`Wants=cs71-web.service` so it starts
once SvelteKit is up.

`systemd/cs71-vision.service` (PI-VISION-001/002/003, ADR-0013) follows the
same design: `RestrictAddressFamilies=AF_UNIX` (it reaches `cs71d`'s socket to
read operation outcomes, PI-VISION-002, and serves its own dataset api,
PI-VISION-003 — nothing more, so no `AF_INET`/`AF_INET6` the way `cs71-web`
needs for its loopback port), and `DeviceAllow=/dev/cs71vision rw` is its own
camera symlink, disjoint from the controller's. Its *effective* `Group=` is
`cs71-api` — not a `SupplementaryGroups=` grant, but its own primary group at
runtime, the same shape `cs71d.service` itself uses (`User and groups`,
above): that one directive both lets it reach `cs71d`'s socket as a client
and makes its own dataset api socket come out `cs71-vision:cs71-api`, so
`cs71-web` can reach it the same way it already reaches `cs71d`'s.
`StateDirectory=cs71-vision` is where `vision.db` lives;
`RuntimeDirectory=cs71-vision` is where the dataset api socket lives,
recreated fresh on every start like `cs71d.service`'s own `RuntimeDirectory=`.
It gates capture on its own camera the same way `cs71d.service` gates on the
controller: `BindsTo=dev-cs71vision.device` plus
`ConditionPathExists=/dev/cs71vision` — the dataset api and correlation loop
share that same gate, since both are meaningless without the service running
at all. `tests/smoke-test.sh` runs the same derived-unit trick against the
fixture backend, since there is no real camera on the CI runner either — and,
once cs71d-smoke is up, points the derived unit's `daemon_socket_path` at
that real running instance and queries its own dataset api as `cs71-web`, so
the `cs71-api` group grant is proven for real in both directions, not just
declared.

## udev

`udev/99-cs71.rules` matches USB vendor ID, product ID **and serial
number** — not vendor/product alone, so it cannot pick up a different unit of
the same adapter model, and it does not match every generic USB-serial
device on the bus. No adapter has been approved yet
(`docs/architecture/deployment-and-operations.md`); the checked-in file has
`@@VENDOR_ID@@`/`@@PRODUCT_ID@@`/`@@SERIAL@@` placeholders that match
nothing until `install.sh` substitutes them from installer arguments — the
values are hardware evidence recorded during PI-HIL-001, not something this
repository invents. The rule tags the device `TAG+="systemd"` with
`ENV{SYSTEMD_WANTS}="cs71d.service"`, so the service starts the moment the
adapter is plugged in rather than racing boot-time unit ordering against a
path that might not exist yet.

`udev/98-cs71-vision.rules` matches the same way for the classifier camera,
on `SUBSYSTEM=="video4linux"` rather than `tty`, with one deliberate
difference: vendor ID and product ID only, no serial number. `99-cs71.rules`
needs a serial number because "any generic USB-serial adapter" is a broad
class it must not accidentally match; this rule matches one specific camera
module already chosen for this appliance
(`3DModels/Classifier/CameraV2`), where exactly one unit is ever expected to
be attached, and many inexpensive UVC modules do not reliably program a
unique USB serial string in the first place. `install.sh`'s
`--camera-vendor-id`/`--camera-product-id` are optional, unlike the
controller's identity arguments: omitting them installs and enables
`cs71-vision.service` with a rule that matches no real device yet, the same
graceful "nothing to do" state the checked-in file is always in before
substitution — existing `install.sh` callers (`tests/smoke-test.sh`
included) keep working unmodified.

## Caddy

`caddy/Caddyfile.cs71` is the entire site: one host block, proxying only to
`127.0.0.1:<port>`. There is no route to the daemon socket, the daemon API,
a static secret or a SQLite file in it, because there is no other route in
it at all. TLS is Caddy's own automatic certificate management, which falls
back to its internal CA for a hostname with no public DNS — the private-LAN
default this appliance assumes throughout
(`docs/architecture/vision-and-scope.md`). `flush_interval -1` is there
because the `/events` SSE stream needs each write flushed immediately, not
buffered.

## Installing

```sh
sudo appliance/ops/install.sh \
  --hostname cs71.local \
  --vendor-id 0403 --product-id 6001 --serial <adapter-serial> \
  --camera-vendor-id 0403 --camera-product-id 6002 \
  --web-port 3000 \
  --start
```

Run this from a checkout of the whole repository, on the target machine
itself — it builds the web workspace's native modules (`better-sqlite3`,
`@node-rs/argon2`) on that machine on purpose, so they match its actual
architecture rather than whatever built them. Without `--start` it installs
and enables all three services but does not start them, which is what the
`appliance-ops` CI job's static checks exercise (it never has a real
adapter or camera to start against anyway). The two `--camera-*` arguments
are optional, unlike the controller's own identity — see the udev section
above.

**`tsx` ships as a real `dependencies` entry, not a devDependency,
deliberately.** `install.sh` runs a full `npm ci` to get every build tool
SvelteKit needs, builds, then `npm prune --omit=dev` — everything except
`dependencies` is gone from the deployed `/opt/cs71/web/node_modules`
afterward. The one-time bootstrap-token CLI
(`appliance/web/scripts/issue-bootstrap-token.ts`) still has to run *after*
that prune, on the box, against the box's own fresh `web.db` — so whatever
runs it has to survive the prune too.

**The bootstrap CLI is the first thing to ever open `web.db`, deliberately.**
It runs, as the `cs71-web` identity, before either service starts — creating
and migrating the database itself — so the service that starts afterward
just opens what is already there instead of racing a second process to
migrate the same empty file.

## Backup, restore and upgrade

`backup.sh` takes a SQLite-consistent online backup of `machine.db`,
`web.db` and — when it exists — `vision.db`
(`sqlite3 ... .backup`, which needs neither service stopped) plus
`cs71d.toml`/`web.env`, into a timestamped directory under
`/var/lib/cs71-backups`, with a checksummed `manifest.json`
(`lib/manifest.py`) recording the source commit and each workspace's own
version — read from `/opt/cs71/ops/release-info.json`, which `install.sh` and
`upgrade.sh` write once at build time rather than `backup.sh` introspecting a
checkout that a periodic timer run has no guarantee is even still there.
`vision.db` is optional in both the backup and the manifest: an appliance
upgraded from a pre-PI-VISION install may not have one yet, and that must
never fail a backup that only ever needed `machine.db`/`web.db` to work.
No service-token file is ever included: a restored backup should bring
back data and configuration, never a credential, and a restore never needs
one — the credential files already on the box are untouched by it. Every
attempt, success or failure, writes exactly one
`/var/lib/cs71d/backup-status.json` — `{"ok": bool, "completed_at": ...}` —
which is the only thing `cs71d`'s own `BackupFreshnessMonitor`
(`appliance/daemon/src/cs71d/storage_health.py`) ever reads; the daemon never
runs a backup itself; it only refuses new work once that file says no
successful one has happened recently enough (see the section below).
`systemd/cs71-backup.timer` runs it daily; `install.sh` copies `backup.sh` and
`lib/manifest.py` to `/opt/cs71/ops` specifically so the timer keeps working
after the checkout that installed it moves, updates or is deleted —
`restore.sh` and `upgrade.sh` are not copied there, and are meant to be run
from an up-to-date checkout, the same way `install.sh` itself is.

`restore.sh --from <backup dir>` verifies the manifest's checksums and each
present database's `PRAGMA integrity_check` *before* touching anything live,
stops `cs71-web.service`/`cs71-vision.service` then `cs71d.service`, installs
the databases and configuration (`vision.db` too, when the backup has one),
then starts the daemon and proves it actually answers
(`GET /v1/health/live` through its own socket, with its own credential)
before starting the web service and proving the same
(`GET /login` on its loopback port) — the "restore is validated by integrity
check and application read-only smoke test" contract in
[data-and-persistence.md](../../docs/architecture/data-and-persistence.md).
`cs71-vision.service` is started too, best-effort: a fresh or camera-less
install never brings it up at all (`ConditionPathExists=/dev/cs71vision`),
and that absence is not a restore failure. When it does come up, its own
dataset api (PI-VISION-003) is queried the same way (`GET /v1/dataset`
through its socket) — logged as a warning rather than failing the restore,
since sorting does not depend on `cs71-vision`. Any daemon or web failure
stops the script rather than declaring success; the runbooks in
`deployment-and-operations.md` take over from there.

`upgrade.sh` backs up first, stops web and vision then daemon, rebuilds the
web workspace, the daemon venv and the vision venv from the current checkout
(the same `build_web_workspace`/`build_daemon_venv`/`build_vision_venv`
`install.sh` itself calls, in `lib/common.sh`, so none of the three ever
drift apart), then starts the daemon and the web service the same validated
way `restore.sh` does, and the vision service best-effort. There is no
separate migration-runner command: opening `machine.db`/`web.db`/`vision.db`
*is* the forward-only, checksummed migration, so "apply migrations" and
"start the daemon"/"start the web service" are the same step here, not two.
Any failure before the web service is confirmed healthy on the new build
rolls back: the previous `/opt/cs71/web`, `/opt/cs71/daemon` and (if it
existed before the upgrade) `/opt/cs71/vision` are swapped back in, and
`restore.sh` is called against the pre-upgrade backup to bring the data back
too — reusing its own stop → verify → install → start → smoke-test sequence
rather than a second copy of it. If the rollback itself fails, the script
says so loudly and stops; that is a "call a human" situation the deployment
runbook owns, not something a script should keep guessing at.

## The daemon's own durability monitor

`cs71d`'s production profile carries a `DurabilityMonitor`
(`appliance/daemon/src/cs71d/storage_health.py`,
`production_durability_monitor`) that two things beyond a failed journal
write can trip: free space beside `machine.db` falling under a fixed 500 MiB
floor, and `/var/lib/cs71d/backup-status.json` being absent, recording a
failed backup, or older than 48 hours (`cs71-backup.timer` runs daily, so
that is one missed run of slack). Either one latches the machine exactly the
way a failed journal write already does —
`journal_available` goes false, `/v1/health/ready` reports `ready: false`
with the reason, and new operations are refused — because both threaten the
same guarantee a journal write does: something admitted now might not be
durably recoverable. The check re-runs on every readiness poll and before
every admission, so the fault surfaces even when nothing is being submitted,
not only once a write is attempted. Like a journal fault, it does not clear
itself; remediating the disk or the backup and restarting `cs71d` is what a
technician does next. Development and test profiles carry no monitor at all —
their databases live in throwaway paths with no installed backup timer behind
them, so there is nothing meaningful to watch there.

## What `tests/smoke-test.sh` does and does not prove

It runs the real `install.sh`, then starts the real `cs71d`/`cs71-web`
services — as derived units with the udev/device gate stripped and a stub
`/dev/cs71` file in its place, on the simulator backend — under their
unmodified sandbox directives, and checks, for real: the socket comes out
`cs71d:cs71-api` mode `0660`; the `cs71-web` identity can reach it with its
own credential and get a real answer; that same identity cannot read the
serial-device stub; the Node process answers on its loopback port under
`ProtectSystem=strict` and the rest; and a process carrying the daemon's own
sandbox properties is kernel-refused when it tries to open an `AF_INET`
socket. This runs in CI on `ubuntu-latest` — a real Linux host, real systemd,
real users — not a mock of any of it.

It then runs a real `backup.sh` against the databases those services just
wrote, verifies the manifest and marker for real, and runs a real
`restore.sh` — through the daemon's actual, fixed unit names (`cs71d.service`,
`cs71-web.service`), not the derived `-smoke` ones, by pointing those real
names at the same simulator-backed unit content for the duration of the
drill and putting the originals back afterward. That lets `restore.sh` run
completely unmodified — the exact script and exact unit names a real restore
uses — while still only ever starting the simulator backend, for the same
DTR-gate reason the rest of this script does. `upgrade.sh`'s rebuild step is
not run here (it would just repeat `install.sh`'s own build under a slower
name); its ordering, its rollback path calling `restore.sh`, and its
backup-before-anything-else sequencing are checked structurally instead, in
`tests/test_artifacts.py`.

It also derives a `cs71-vision-smoke.service` the same way, on the fixture
camera backend, and checks it stays active and actually logs a captured
frame (not just "active" — `systemctl is-active` alone would not prove the
capture loop is really running). Its `daemon_socket_path` points at the
real, already-running `cs71d-smoke.service` from earlier in the script —
real proof `Group=cs71-api` and `RestrictAddressFamilies=AF_UNIX`
actually let it reach the daemon, not just that the fixture camera works in
isolation: the check confirms no "could not reach cs71d" error was logged
and that `vision.db` was actually created, `cs71-vision:cs71-api` owned,
proving `DatasetStore.open()` succeeded for real. It does not drive an
actual sort operation through `cs71d-smoke` to prove a labeled example gets
recorded end to end — `Correlator`/`DaemonClient` already have thorough
unit/integration coverage of that logic (`appliance/vision/tests/`,
including a real fake HTTP server over a real `AF_UNIX` socket), and this
smoke test's job is the sandbox/packaging layer underneath it, not a second
copy of that coverage.

**PI-VISION-003's own dataset api socket is checked the same way.** The
script waits for `/run/cs71-vision/cs71vision.sock` to appear (systemd's
`RuntimeDirectory=`), asserts it is `cs71-vision:cs71-api` 0660 - the same
shape `/run/cs71/cs71d.sock` already is - and then, running *as* `cs71-web`
with `cs71-web`'s own copy of the shared credential, issues a real
`GET /v1/dataset` through it and checks for `200`. That is real proof the
new `Group=cs71-api` grant lets `cs71-web` reach a socket `cs71-vision`
itself created, not only one `cs71d` created - the two are different claims,
and PI-VISION-002 only ever proved the first.

What it cannot prove, and does not claim to: that the production profile
(`backend = "serial"`) starts at all. It does not, on any Linux host,
Pi included — Linux DTR is `NOT_EXECUTED`
(`docs/architecture/security-and-safety.md`, SAF-07), so
`cs71d.device.create_transport_factory` refuses to open a real port outright.
That is not a smoke-test gap; it is the DTR gate doing exactly what it is
for. Closing it is PI-HIL-001, and needs the physical adapter, wiring and
instrumentation this backlog item was never scoped to have. The same is
true of `cs71-vision`'s `V4L2Camera`: nothing here proves it opens a real
camera correctly, only that its own refusal path and the fixture-backed
service packaging work. Real camera evidence is PI-HIL/hardware-evidence
territory, the same class of gap.

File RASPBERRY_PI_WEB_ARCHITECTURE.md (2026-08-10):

# Raspberry Pi 5 CS7.1 Control Appliance — Executive Summary

> **Canonical detailed architecture:** [docs/architecture/README.md](docs/architecture/README.md). This document is an executive summary, not a competing source of normative detail. Firmware wire behavior remains canonical in [ArduinoCode/PROTOCOL_V2.md](ArduinoCode/PROTOCOL_V2.md), and the existing host-library scope remains canonical in [host/README.md](host/README.md).

## Direction

The MVP is a native Raspberry Pi OS appliance for one CS7.1 controller:

```mermaid
graph LR
  B[Operator browser] -->|HTTPS| C[Caddy]
  C --> W[SvelteKit SSR Node.js BFF/UI]
  W -->|HTTP/JSON + SSE over Unix domain socket| D[Python cs71d]
  D -->|USB serial via cs71_protocol| F[CS7.1 firmware]
  E[Physical E-stop / motor isolation] -. independent .-> F
```

- SvelteKit is the browser-facing SSR application and BFF. The browser never reaches `cs71d`, USB or serial directly.
- Python `cs71d` is the sole serial owner and uses the existing `cs71_protocol` boundary. A dedicated worker serializes machine I/O.
- The internal daemon API is versioned HTTP/JSON over a Unix domain socket; commands use REST and updates use SSE, not WebSocket for MVP.
- `cs71d` and SvelteKit own separate SQLite databases; they correlate with `operation_id` and never share writes.
- systemd, udev stable device identity and Caddy provide the native deployment model; containers are excluded from MVP.

## Safety and evidence boundary

A command is not user-complete until `cs71d` records a trusted, correlated firmware terminal. Timeout, disconnect, malformed/CRC/interleaved data, failed recovery or journaling failure is never represented as success; it produces failure or `UNCERTAIN`. Priority software stop bypasses ordinary work, but it is **not an E-stop**. Physical energy isolation remains independent.

Linux/POSIX DTR behavior is **NOT_EXECUTED** and unqualified. The current host transport deliberately guarantees pre-open DTR suppression only for the Windows pyserial backend. Raspberry Pi unattended/pilot operation requires the instrumented DTR experiment and hardware gate described in [deployment-and-operations.md](docs/architecture/deployment-and-operations.md). Simulator evidence cannot satisfy DTR, physical motion, stop, USB or HIL gates.

## Where to read details

| Need | Canonical document |
| --- | --- |
| goals, scope and targets | [vision-and-scope.md](docs/architecture/vision-and-scope.md) |
| boundaries and failures | [system-context.md](docs/architecture/system-context.md) |
| worker, state, recovery and stop | [runtime-and-domain.md](docs/architecture/runtime-and-domain.md) |
| daemon REST/SSE contract | [api-and-events.md](docs/architecture/api-and-events.md) |
| persistence, security and deployment | [data-and-persistence.md](docs/architecture/data-and-persistence.md), [security-and-safety.md](docs/architecture/security-and-safety.md), [deployment-and-operations.md](docs/architecture/deployment-and-operations.md) |
| quality evidence, roadmap and PR tasks | [testing-and-quality.md](docs/architecture/testing-and-quality.md), [roadmap.md](docs/architecture/roadmap.md), [backlog.md](docs/architecture/backlog.md) |
| accepted decisions and traceability | [adr/README.md](docs/architecture/adr/README.md), [traceability.md](docs/architecture/traceability.md) |

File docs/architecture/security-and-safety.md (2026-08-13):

# Security and Safety

## Assets, threats and surfaces

| Asset | Primary threat | Control |
| --- | --- | --- |
| Machine motion and operator safety | unauthorized, stale or ambiguous command | RBAC, CSRF, generation checks, single serial owner, fail-closed `UNCERTAIN`, physical E-stop. |
| Serial device/session | competing owner, device substitution, malformed response | dedicated user/lock, udev stable identity, strict `cs71_protocol`, least privilege. |
| Local accounts/sessions | credential theft, fixation, CSRF | Argon2id, opaque rotating sessions, secure cookies, CSRF tokens/origin checks, rate limits. |
| Daemon API | LAN/browser exposure or confused deputy | Unix domain socket only, socket group/modes, BFF identity, Caddy never proxies it. |
| Journals/configuration | tampering, data loss, false completion | separate SQLite ownership, permissions, backups, migration checks, journal failure blocks motion. |
| Release artifacts | dependency/supply-chain compromise | pinned/reviewed dependencies, SBOM/license/vulnerability CI, signed/provenanced release process when adopted. |

Attack surfaces are HTTPS forms/SSE, Caddy configuration, Node dependency tree, Unix socket, service environment/configuration, USB device and firmware serial frames, local console, backups and upgrade artifacts. The appliance is designed for a trusted private LAN, not as an Internet-exposed service.

## RBAC matrix

| Capability | Viewer | Operator | Administrator |
| --- | :---: | :---: | :---: |
| Read snapshot/history/faults | yes | yes | yes |
| Software stop | yes | yes | yes |
| Connect, home, sort, feed, start/stop a routing run (PI-VISION-009) | no | yes | yes |
| Retrain/activate/roll back classifier model (`vision.train`) | no | yes | yes |
| Recovery/reset | no | no | yes, explicit confirmation |
| Change permitted configuration | no | no | yes |
| Manage users/provisioning | no | no | yes |
| Direct protocol command/device path | no | no | no |

SvelteKit enforces these rules server-side before calling `cs71d`; browser components are not an authority. The daemon accepts only its BFF service identity and restricted actor attribution—not arbitrary browser credentials or roles.

`vision.train` (PI-VISION-005, ADR-0013) is a deliberate departure from this table's own pattern of reserving impactful/irreversible actions to `administrator`: retraining, activating and rolling back a classifier candidate never touches machine motion, `cs71d`'s command surface, or either database `cs71d`/`cs71-web` own, so it is granted at the `operator` row instead. It gates `cs71-vision`'s own HTTP surface (`appliance/vision/src/cs71vision/api.py`, PI-VISION-003/004/005) the same way every other capability gates `cs71d`'s.

**`machine` is not a row of this table** (PI-VISION-007, ADR-0013): it is not a human role reached through a browser session at all, so it does not sit on the Viewer/Operator/Administrator ladder this matrix orders — it is a separate, narrower vocabulary the daemon's own contract adds. It may submit exactly one thing, `sort`, and nothing else, under any configuration, and only when authenticated with its own distinct service credential (`machine_service_token_path`, never the BFF's) — the daemon checks that the claimed role and the credential that authenticated the request agree in both directions, so neither a browser-attributed request nor the ordinary shared credential can ever produce a machine-attributed command, and the machine credential can never be used to claim a human role either. It cannot reach `machine.recover`, `config.write` or `users.manage` under any circumstance (ARCH-06); this is enforced at the daemon boundary (`cs71d.api._commanding_actor`), not only by the fact that `cs71-web` never presents this credential. Since PI-VISION-008, `cs71-vision` is wired to actually act as this role — `cs71vision.autonomy.Autonomist` is the only thing in this codebase that ever presents the machine credential, and only for a `sort` that has already cleared both the primer gate (SAF-09) and a per-class confidence threshold (`may_autonomously_sort`). The mechanism being wired is not the same as the policy being active: `autonomy_thresholds` defaults empty, so a fresh installation autonomously sorts nothing until an operator explicitly configures a class.

## Authentication and session protections

Initial provisioning is local-console/installer mediated and creates a single administrator through a one-time, expiry-bound mechanism; no default password ships. Password hashes use Argon2id with current calibrated parameters. Cookies are `Secure`, `HttpOnly`, `SameSite` appropriate to the single origin, scoped narrowly, rotated after login/privilege change and revoked on logout/password disable. State-changing requests require per-session CSRF validation plus Origin/Referer policy. Login, session and command routes have request-body, rate and concurrency limits. Audit logs redact credentials, cookies, CSRF values and secrets.

## Unix socket and service hardening

The socket lives in `/run/cs71/cs71d.sock`, owned by `cs71d` with a dedicated group readable/connectable only by the SvelteKit service user; no TCP listener is created. `cs71d` has access to the configured serial device and its state directory only. SvelteKit can connect to the socket but cannot open the serial device or `machine.db`. Use separate unprivileged users, restrictive `umask`, systemd credentials/environment files with root ownership, `NoNewPrivileges=yes`, private temporary directories, read-only system paths where practical, restricted address families, capability bounding, device allow-lists, memory/CPU limits and syscall protection after compatibility testing. Hardening must not conceal required USB access or journal faults.

Caddy terminates TLS and proxies only to loopback SvelteKit. Production/pilot certificates, hostname and TLS policy are explicitly configured; development may use plain loopback/LAN only under documented profile restrictions. Secrets are generated per installation, never committed, redacted in logs and rotated by documented procedure.

## Safety invariants

| ID | Invariant |
| --- | --- |
| SAF-01 | Only the serial worker in `cs71d` accesses the controller serial session. |
| SAF-02 | No state-changing operation is successful without a trusted, correlated firmware terminal. |
| SAF-03 | Timeout, USB loss, malformed/CRC/interleaved protocol response, journal failure or failed recovery cannot become success; affected state is `UNCERTAIN` or failed. |
| SAF-04 | Priority software stop bypasses ordinary command admission, but software stop is never labelled or relied on as E-stop. |
| SAF-05 | Snapshot-generation mismatch rejects motion before serial I/O; browser/SSE retry never replays an action without idempotency semantics. |
| SAF-06 | Node/SvelteKit availability is not a serial ownership dependency; its restart does not interrupt an active daemon operation. |
| SAF-07 | POSIX/Linux DTR behavior is **NOT_EXECUTED** and unqualified until physical experiment evidence closes the gate. |
| SAF-08 | Simulator evidence cannot satisfy any hardware, DTR, physical-stop or production-release gate. |
| SAF-09 | Primer-presence classification never authorizes autonomous action; a flagged or ambiguous case always requires operator confirmation, independent of manufacturer-classification confidence or the autonomy configuration. |

`cs71vision.primer.requires_operator_confirmation` (PI-VISION-010) is
SAF-09's enforcement point: `True` unless the primer axis is confidently
`False`, taking no configuration parameter - there is no argument that
could ever be passed to bypass it. No trained primer detector exists yet,
so the axis is always `None` (unknown) today, meaning confirmation is
currently always required; this matches SAF-07/SAF-08's own posture that
this axis is not "closed" by software evidence alone. `cs71vision.autonomy.may_autonomously_sort`
(PI-VISION-008) consults this function before ever attempting an
autonomous sort, in addition to its own separate manufacturer-class
confidence gate - checked first and unconditionally, so no per-class
threshold can ever override it.

Unsafe or uncertain behavior is explicit: a disconnect or non-correlatable result disables dependent actions, prominently displays `UNCERTAIN`, preserves evidence, and requires the authorized recovery procedure. “Ready” is not a claim of physical clearance, homing, energy isolation, or E-stop availability. A physical emergency stop and guarded motor-power path are mandatory operational controls outside the software trust boundary.

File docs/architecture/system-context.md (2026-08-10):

# System Context and Containers

## C4 system context

```mermaid
flowchart LR
    operator[Operator browser]
    subgraph appliance["Raspberry Pi 5 appliance"]
        web[SvelteKit SSR<br/>Node.js BFF/UI]
        daemon[cs71d<br/>Python machine-control daemon]
    end
    controller[CS7.1 controller<br/>firmware, motors, sensors]
    estop[Physical E-stop /<br/>motor isolation]
    operator -->|HTTPS| web
    web -->|internal HTTP/JSON + SSE<br/>Unix domain socket| daemon
    daemon -->|USB serial 9600 8N1| controller
    estop -. physical safety circuit .-> controller
```

The browser cannot reach the Unix domain socket, serial device, controller, or daemon API. SvelteKit authenticates and authorizes intent; it does not own motion timing. Firmware controls low-level movement and is not a proof that physical motion completed unless a trusted terminal and HIL evidence support the specific claim. The E-stop path is outside software control.

## C4 container view

```mermaid
flowchart LR
    operator[Operator]
    subgraph pi["Raspberry Pi 5 / Raspberry Pi OS"]
        caddy[Caddy<br/>TLS edge]
        web[SvelteKit SSR<br/>Node.js]
        daemon[cs71d<br/>Python]
        webdb[(web.db<br/>SQLite)]
        machinedb[(machine.db<br/>SQLite)]
    end
    controller[CS7.1 controller]
    operator -->|HTTPS| caddy
    caddy -->|loopback HTTP| web
    web -->|HTTP/JSON + SSE<br/>/run/cs71/cs71d.sock| daemon
    web -->|exclusive read/write| webdb
    daemon -->|exclusive read/write| machinedb
    daemon -->|USB serial| controller
```

`web.db` and `machine.db` are distinct stores with no shared writes; cross-service correlation uses `operation_id`. See [data-and-persistence.md](data-and-persistence.md).

## Trust boundaries

| Boundary | Rule |
| --- | --- |
| Browser → Caddy/SvelteKit | Treat all input, cookies and SSE reconnect headers as hostile; enforce authentication, RBAC, CSRF and validation. |
| SvelteKit → `cs71d` | Local authenticated service boundary via Unix socket permissions; BFF maps users to attributable command metadata. It is not a public API. |
| `cs71d` → controller | Only the serial worker opens the configured stable device; parsing/correlation uncertainty is fail-closed. |
| Software → physical plant | Software stop is a requested firmware command, not a safety-rated E-stop; physical isolation remains independent. |

## External dependencies and failure domains

| Dependency/failure domain | Impact | Required behavior |
| --- | --- | --- |
| Browser or browser SSE connection | Lost presentation only. | SvelteKit resumes or obtains a snapshot; no serial action is retried by browser reconnect. |
| Caddy/SvelteKit restart | Web unavailable or sessions may require revalidation. | `cs71d` and serial worker continue; active daemon operation is unaffected. |
| Unix socket/daemon failure | BFF cannot control/observe. | UI reports unavailable; daemon restart recovers conservatively. |
| USB adapter/device loss | Machine state may be unknown. | `cs71d` marks `UNCERTAIN`/disconnected, invalidates motion assumptions and requires verified recovery. |
| Firmware parse, CRC, timeout or interleaving fault | Correlation is unsafe. | `cs71d` follows `cs71_protocol` recovery; no success result. |
| SQLite/journal or disk fault | Durable audit/lifecycle may be incomplete. | Surface fault and block new state-changing operations; never silently continue. |
| Power loss | Process and physical state may diverge. | On restart, assume no prior operation completion; re-establish verified session and require recovery/homing policy. |

Detailed runtime behavior is canonical in [runtime-and-domain.md](runtime-and-domain.md).

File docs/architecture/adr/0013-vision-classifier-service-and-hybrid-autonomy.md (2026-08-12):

# ADR-0013: Vision classifier as a third appliance service with configurable routing and hybrid autonomy

**Status:** Proposed<br>
**Date:** 2026-08-12

## Context

Headstamp classification today runs entirely outside this repository, on a
separate Windows PC ("AI Sorter", `ArduinoCode/PROTOCOL.md`'s minimum
supported version `1.1.46`) wired directly to the controller. The goal of
this decision is to bring that capability onto the appliance itself —
Arduino Uno plus Raspberry Pi 5, no separate Windows PC — as a new,
explicitly out-of-MVP capability (`vision-and-scope.md` lists "classifier
implementation" under MVP exclusions; this ADR is what would lift that
exclusion for a later phase).

Facts this decision is built on, gathered before writing it rather than
assumed:

- Cases reaching this stage are already sorted by caliber with a physical
  sieve upstream of the appliance. What remains to classify is
  **manufacturer headstamp**, and a single batch may contain several dozen
  distinct manufacturers.
- The physical machine has **8 output chutes by default**
  (`SORTER_SLOT_COUNT` in `ArduinoCode/CS71_Arduino/CS71_Arduino.ino`), with
  8- or 10-slot printable attachments; the daemon API accepts up to
  `MAX_API_SLOT = 63` (`appliance/daemon/src/cs71d/api.py`), but that is a
  protocol ceiling, not a statement about what is mechanically buildable.
  Several dozen manufacturer classes do not fit a handful of physical
  chutes — every design here has to say what happens to the classes that
  do not get their own chute.
- Cases may or may not carry a live/unfired primer. This is not "one more
  classification label": misjudging it is a physical-risk category this
  project already treats with extreme conservatism everywhere else (E-stop
  independence, DTR gate). It gets the same treatment here.
- No trained model and no labeled dataset exist yet, for headstamps or for
  primer presence. Whatever this ADR proposes has to work starting from
  nothing.
- `cs71d`'s command API validates every `Actor.role` against a fixed set,
  `API_ROLES = {viewer, operator, administrator}`
  (`appliance/daemon/src/cs71d/api.py`) — there is no concept today of a
  command attributed to anything other than a human web session. Every
  durable operation, RBAC capability and audit row currently assumes a
  person made the decision.
- The v2 "feed" lifecycle is gated `NOT_EXECUTED`
  (`FEED_LIFECYCLE_GATE`, `appliance/daemon/src/cs71d/adapters.py`) — the
  same evidence-status posture as the Linux DTR gate. There is currently no
  software-driven "a case is now in position" signal a vision component
  could trigger a capture from; that gate closing is a precondition for a
  fully autonomous capture→classify→sort loop, not something this ADR can
  route around.
- The camera hardware already specified in
  `3DModels/Classifier/CameraV2/Camera Assembly V2.pdf` is a plain USB VGA
  UVC module (640×480, driverless, works with the OS's default camera app on
  Windows today) plus a 5V LED ring and a 12V fan. On Linux this is a
  standard V4L2 device — no CSI ribbon, no `libcamera` dependency.

## Decision

Add a **third appliance service**, provisionally named `cs71-vision`, that
owns the camera and inference pipeline — the same single-responsibility
split `cs71d` (sole serial owner) and `cs71-web` (browser BFF) already use,
not folded into either. `cs71d` keeps owning the controller and the safety
model; `cs71-vision` never touches the serial device directly and only ever
asks `cs71d` to act, the same way `cs71-web` does today.

**Data comes from ordinary operation, not a separate labeling effort.**
Phase 0 ships no classifier at all: while an operator sorts by hand as they
do today, `cs71-vision` records the camera frame alongside the slot the
operator actually chose (correlated by `operation_id`), building a labeled
dataset for free. No model is trained, and nothing is classified
automatically, until there is real data to train on.

**Routing is operator-selectable configuration, not one hardcoded
strategy.** Several dozen manufacturer classes into 8–10 chutes has more
than one defensible mapping, and different runs may want different ones.
`cs71-vision` exposes a small set of routing profiles, selected through the
web UI the same way other daemon configuration is already changed
(`OperationDomain.configure`/`ConfigurationValues`):

- a fixed class→chute map with one overflow chute for everything else,
- dynamic per-batch assignment (the first N distinct classes seen in this
  run claim a chute; the UI must then show the operator which chute means
  which class *for this run*, since that mapping is not stable across
  runs),
- a two-pass mode: a first pass sorts into coarse groups, a second pass (run
  as its own job against one group's output) sorts that group more finely.

**Autonomy is confidence-gated per class, starting conservative.** Below a
configured confidence threshold, a case is held for the operator to confirm
through the web UI rather than sorted automatically. The threshold is
expected to start high (mostly manual, matching Phase 0/1's thin dataset)
and only relax as the model is retrained on more data, including the
corrections an operator makes to low-confidence predictions.

**Primer presence is never decided by confidence alone.** A case flagged,
or ambiguous, for a live/unfired primer always requires operator
confirmation, independent of the routing/manufacturer confidence threshold
and independent of how the autonomy setting above is configured. This
mirrors the DTR gate and E-stop posture already in this codebase: software
does not get to declare a physical-risk judgment safe on its own say-so.

**A command attributed to `cs71-vision` needs a new, narrowly-scoped actor
kind in `cs71d`'s contract**, not a reuse of an existing human role. It is
authenticated by its own service credential the same way `cs71-web` is
today — never a browser session — and is restricted to submitting `sort`
operations only; it can never reach `machine.recover`, `config.write` or
`users.manage`. This is a daemon and OpenAPI contract change
(`API_ROLES`, the `Actor` shape, `appliance/contracts/cs71d-v1.openapi.json`),
not a web-only addition, and every such command still lands in the existing
durable journal and audit trail with this new attribution visible as what
it is — a system decision, not a person's.

**Training and activating a new model version is an operator-facing
action inside `cs71-vision` itself**, mirroring this project's own
backup/upgrade/rollback discipline (`appliance/ops/backup.sh`/`restore.sh`/
`upgrade.sh`) applied to a model instead of a database or release artifact,
rather than a developer-only offline step:

- Per-class example counts are visible *before* training is offered, not
  only after. A class below a hard minimum-example floor is automatically
  excluded from the training run, and the UI states why rather than
  silently omitting it or training on a class too thin to trust.
- Retraining runs as a background job, locally on the Pi 5, in idle time —
  not real-time, not blocking ordinary sorting, no workstation or cloud
  service required.
- A freshly trained model is a **candidate**, not the active model: its
  accuracy per class on held-out examples is shown before it can replace
  what is currently running.
- Both triggering a retrain and activating a candidate as the live model
  are available to `operator`, not gated to `administrator` — a deliberate
  departure from this project's existing pattern of reserving
  impactful/irreversible actions (`machine.recover`, `config.write`) for
  administrators. This needs its own new capability (working name
  `vision.train`), not a reuse of `machine.operate`, since it never touches
  machine motion.
- Training and activation never touch `cs71d`'s command surface — they are
  entirely internal to `cs71-vision`, its own state and its own model
  files — so they need no new `cs71d` actor kind or contract change. The
  actor-kind change above is only for the autonomous `sort` command a
  trained model may eventually issue, not for training itself.
- At least the previously active model version is retained, so an
  activation can be rolled back the same way a bad upgrade already is —
  activation is a durable, versioned switch, never an in-place overwrite.

## Options considered

| Option | Reason selected or rejected |
| --- | --- |
| Third service `cs71-vision`, camera/inference isolated from `cs71d`/`cs71-web` | Selected: keeps `cs71d`'s single-serial-owner discipline and test model intact; matches how this codebase already separates concerns. |
| Fold vision into `cs71d` | Rejected: `cs71d` is deliberately the *sole serial owner and nothing else* — adding a camera/ML workload there breaks that boundary and its safety-review story. |
| Fold vision into the SvelteKit BFF | Rejected: Node.js is a poor fit for camera capture/inference, and the BFF has no device access today by design. |
| Keep classification external on a Windows PC, Pi only orchestrates motion | Rejected: this is the thing the user explicitly wants removed. |
| One hardcoded routing strategy | Rejected: several dozen classes into 8–10 chutes has no single right answer across different batches/use cases; made configurable instead. |
| Reuse an existing human role (e.g. `operator`) for autonomous commands | Rejected: collapses "a person decided" and "a model decided" into the same audit trail entry, which this project's attribution model exists specifically to avoid. |
| Gate retrain/activate to `administrator` only, matching `machine.recover`/`config.write` | Rejected (explicit product choice): training/activation never touches machine motion, so it is granted to `operator` through a new, separate capability instead of following the existing impactful-action pattern by default. |
| No per-class minimum-example floor before training | Rejected: would let a class with a handful of examples produce a confidently wrong model with no signal to the operator about why. |

## Consequences

### Positive

- No separate Windows PC; the whole system is Uno + Pi 5.
- Data collection starts on day one of Phase 0 with zero extra operator
  effort, at essentially no cost or risk (nothing is classified or acted on
  automatically yet).
- Routing strategy stays a configuration choice, not a rewrite, as real
  usage reveals which mapping actually works for a given batch shape.
- The primer-presence rule and the new actor kind keep the existing
  "physical risk is never a software claim" discipline intact rather than
  quietly eroding it for the sake of automation.
- Operators can grow and improve the model themselves, entirely on-device,
  without developer or administrator involvement for routine retraining —
  closes the loop without needing a separate PC for that either.

### Negative

- A new actor kind is a daemon safety-model and contract change, reviewed
  with the same weight as `cs71d`'s existing safety primitives — not a
  small addition.
- Fully autonomous end-to-end operation (capture → classify → sort with no
  operator in the loop) cannot be reached until the feed lifecycle gate
  closes; until then, feed remains a manual/operator-driven step regardless
  of how good the classifier is.
- Dynamic per-batch routing requires new UI (a live chute↔class legend)
  that does not exist anywhere in this codebase today.
- Model quality is bounded by whatever Phase 0 self-labeled data actually
  captures; a biased or thin operator-driven sample yields a biased model,
  and that has to be watched for, not assumed away.
- Granting `operator` a capability that manages a durable, versioned
  artifact (the model) is a new precedent in this RBAC model, which has so
  far reserved that class of action for `administrator`; worth watching for
  scope creep if it becomes a template for other admin-shaped actions later.

## Implementation constraints

- `cs71-vision` never opens the serial device or bypasses `cs71d`'s
  admission path; every sort it triggers goes through the same
  idempotency/generation/durability rules any other command does.
- The new actor kind is added to `API_ROLES` and the OpenAPI contract as an
  additive, versioned change, following the same discipline PI-UI-002's
  `/v1/system` addition already established (additive, not a breaking
  change to `FROZEN_*` contract guards).
- Primer-presence confirmation cannot be bypassed by raising the
  manufacturer-classification confidence threshold; it is a separate gate,
  enforced independently.
- Camera integration targets plain V4L2 (matching the confirmed USB VGA UVC
  hardware in `3DModels/Classifier/CameraV2`); no `libcamera`/CSI dependency
  is assumed unless a different camera is chosen later.
- Until the feed lifecycle gate closes, `cs71-vision` cannot assume a
  software signal for "a case is now in position"; a capture trigger has to
  be designed around that absence (e.g. frame-stability detection) rather
  than waiting on a gate this ADR does not control.
- Training and activation get a new capability (working name `vision.train`)
  granted to `operator` (and `administrator`, since administrators are a
  superset), not a reuse of `machine.operate` — it is added to the RBAC
  matrix in `security-and-safety.md` and `appliance/web/src/lib/server/auth/capabilities.ts`
  the same way any other capability is, not inferred from an existing role.
- The per-class minimum-example floor is enforced before a class is
  included in a training run, not only reported afterward; a class excluded
  this way is still shown in the UI with its count and the floor, not
  silently dropped.
- At least the current and previous model versions are retained on disk so
  activation can be rolled back without a new retraining run.

## Validation and revisit triggers

- Phase 0 exit: a labeled dataset exists from real operator-driven sorting,
  with per-class counts high enough to attempt a first model.
- Phase 1 exit: a first model runs read-only (suggestion only, operator
  always confirms); measured accuracy per class is recorded before any
  autonomy is considered.
- Before relaxing the autonomy threshold for any class: recorded accuracy
  and a false-autonomous-sort rate for that class, not a general "it seems
  to work."
- Before ever reconsidering the "primer presence always confirms" rule:
  dedicated physical trial evidence, reviewed the same way DTR/HIL evidence
  is — this is explicitly not expected to relax on software evidence alone.
- Revisit this ADR if the feed lifecycle gate closes (PI-DOMAIN-003/PI-HIL
  territory), since that changes what "capture trigger" can rely on.
- Before shipping operator self-service activation: confirm the UI always
  shows the candidate's accuracy alongside the currently active model's, so
  an operator cannot activate a worse candidate without seeing that it is
  worse.

## Links

- [Vision and scope](../vision-and-scope.md) (MVP exclusion this ADR
  proposes lifting for a later phase); [System context](../system-context.md);
  [Security and safety](../security-and-safety.md); [Runtime and domain](../runtime-and-domain.md).
- [ADR-0003](0003-python-cs71d-single-serial-owner.md) (why `cs71d` stays
  the sole serial owner and gains no new responsibilities here);
  [ADR-0006](0006-fail-closed-priority-stop.md) (the fail-closed posture
  this decision extends to a new actor kind);
  [ADR-0011](0011-local-auth-rbac-sessions.md) (the RBAC/attribution model
  a machine actor must not silently reuse).
- No backlog epic yet: this ADR is the alignment step requested before one
  is written.

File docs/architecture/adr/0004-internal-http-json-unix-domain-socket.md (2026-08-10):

# ADR-0004: Internal HTTP/JSON over Unix domain socket

**Status:** Accepted<br>
**Date:** 2026-08-10

## Context

The two local processes need observable typed communication without exposing machine control to the LAN. OpenAPI tooling favors HTTP semantics.

## Decision

Use versioned HTTP/JSON over `/run/cs71/cs71d.sock` with filesystem permission-based service access. Do not bind daemon control to TCP.

## Options considered

| Option | Reason selected or rejected |
| --- | --- |
| HTTP/JSON Unix domain socket | Selected: local-only, debuggable and OpenAPI-compatible. |
| Loopback TCP | Rejected: unnecessarily expands exposure. |
| In-process binding | Rejected: conflicts with two-process boundary. |

## Consequences

### Positive

- Clear resource/error semantics and narrow network attack surface.
- SvelteKit can use standard generated clients.

### Negative

- Socket lifecycle/mode/group need service coordination.

## Implementation constraints

- Socket permits only the designated web service identity.
- Caddy never proxies the daemon API.

## Validation and revisit triggers

- Test no TCP listener, socket modes and service connectivity.
- Revisit for a demonstrated remote trusted-control requirement with new security design.

## Links

- [API](../api-and-events.md); [Security](../security-and-safety.md); [PI-API-001](../backlog.md#pi-api-001--serve-openapi-backed-unix-socket-rest-api).

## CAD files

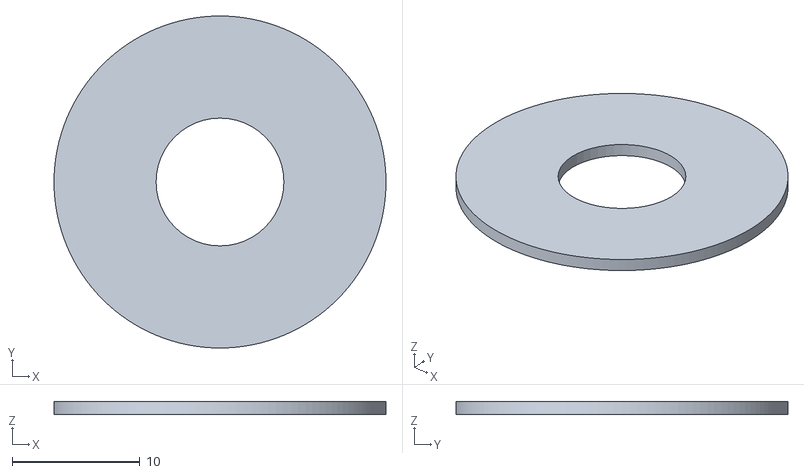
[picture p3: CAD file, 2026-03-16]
CommunityContributions/Misc/SilverBullit/M10KnobShim1mm.stl
26.0 x 26.0 x 1.00

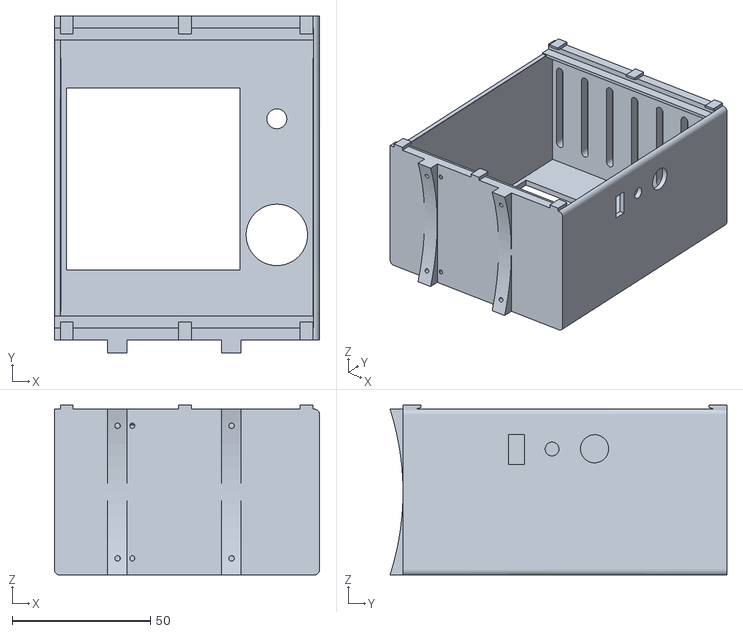
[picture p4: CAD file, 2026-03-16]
CommunityContributions/Misc/SilverBullit/BF556 300 - ElectronicBoxModded62x62.stl
96.0 x 122.0 x 61.5

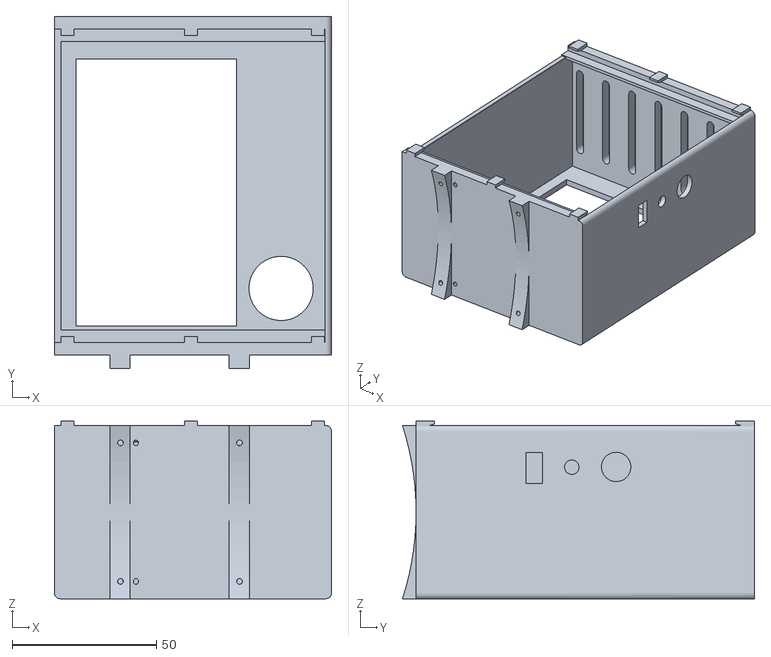
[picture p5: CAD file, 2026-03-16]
CommunityContributions/Misc/SilverBullit/BF556 300 - ElectronicBoxModdedAnotherSize.stl
96.0 x 122.0 x 61.5

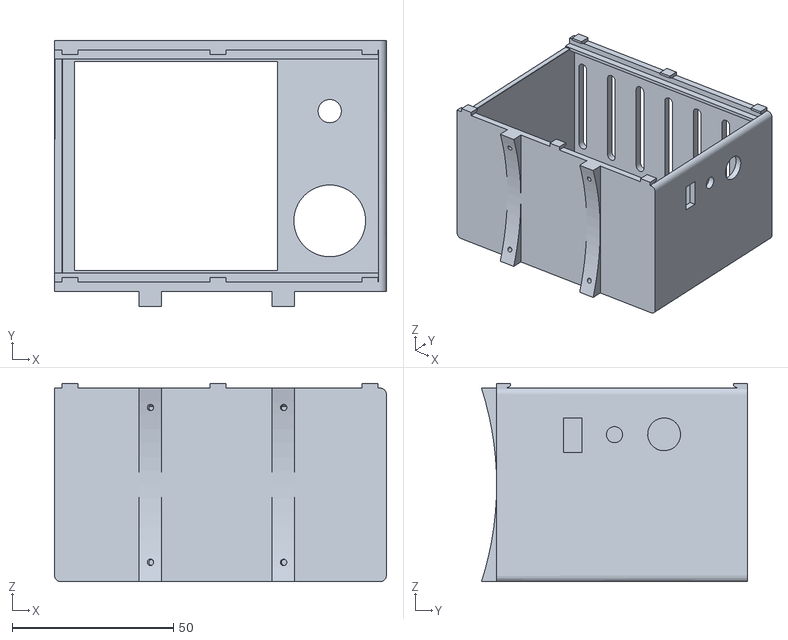
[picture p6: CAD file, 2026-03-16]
CommunityContributions/Misc/SilverBullit/BF556 300 - ElectronicBoxModded62,88x64,8.stl
102.9 x 82.5 x 61.5

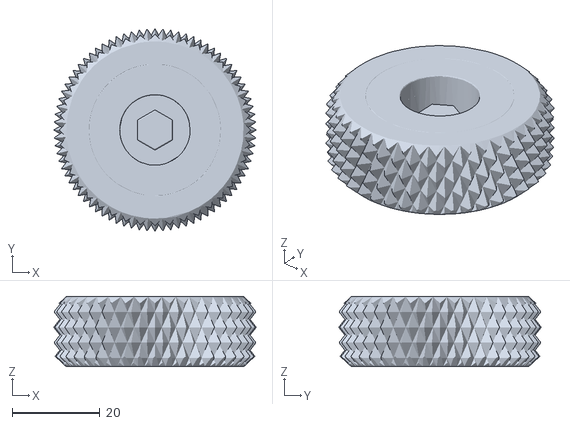
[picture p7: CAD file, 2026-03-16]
CommunityContributions/Misc/SilverBullit/M10HexAllenKnobV4.0d.stl
46.1 x 46.1 x 16.0

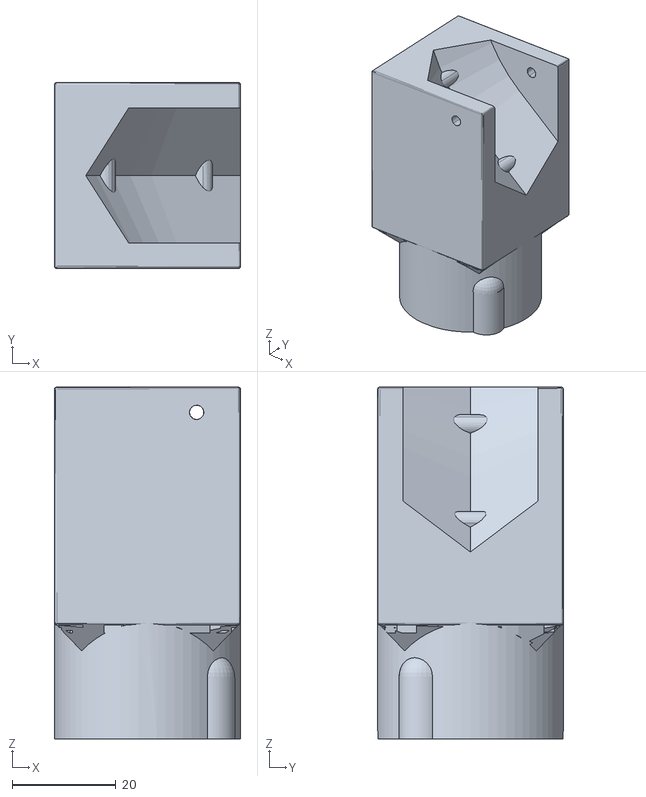
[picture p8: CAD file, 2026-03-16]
CommunityContributions/Misc/SilverBullit/CS7.2 Pipe Bracket_Mod_ExtendedSensorBump.stl
36.0 x 36.0 x 68.0

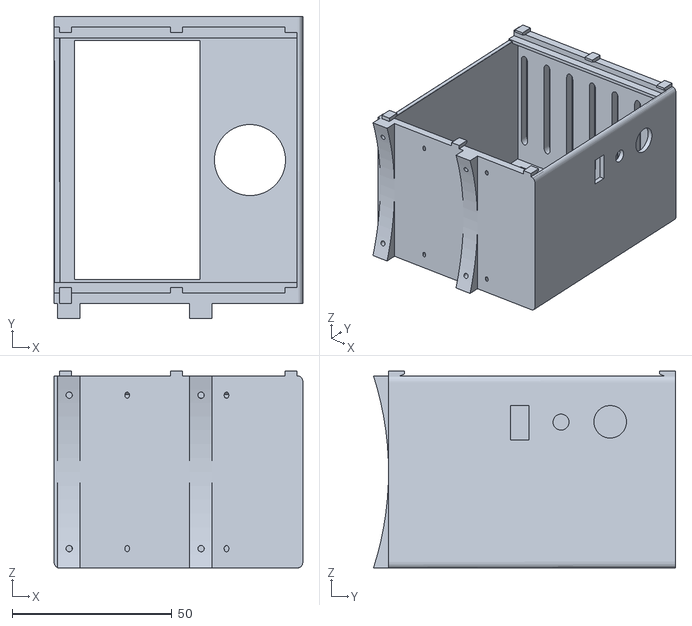
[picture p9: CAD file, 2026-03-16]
CommunityContributions/Misc/SilverBullit/BF556 300 - ElectronicBoxModded39,2x74,8.stl
77.9 x 94.5 x 61.5

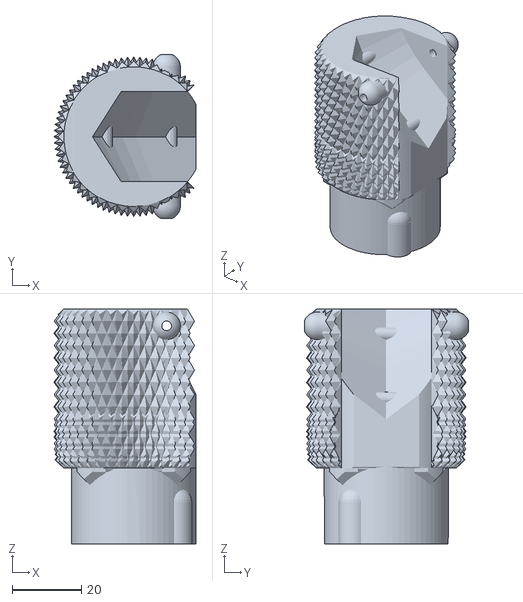
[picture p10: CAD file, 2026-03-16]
CommunityContributions/Misc/SilverBullit/CS7.2 Pipe Bracket_Mod_ExtendedSensorBump_KnurledVersion.stl
41.0 x 47.6 x 68.0

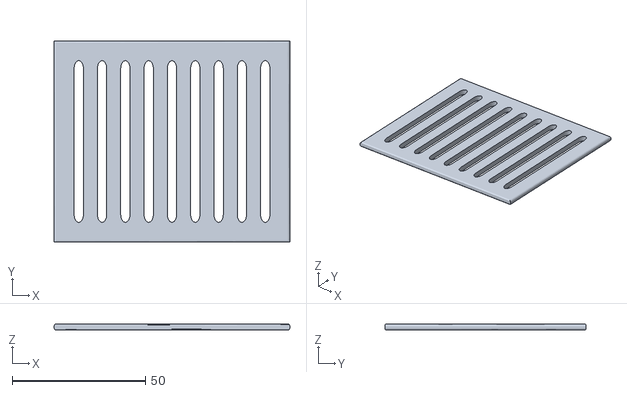
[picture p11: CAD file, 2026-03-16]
CommunityContributions/Misc/SilverBullit/BF556 300 - ElectronicLidModBLUEforgotsizexsizeHorisontal_LidV2.stl
88.5 x 75.5 x 2.40

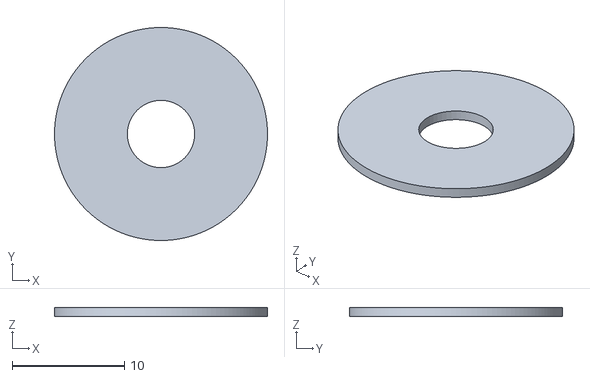
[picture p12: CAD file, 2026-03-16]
CommunityContributions/Misc/SilverBullit/ClassifierBearingShim0.8mm.stl
19.0 x 19.0 x 0.8

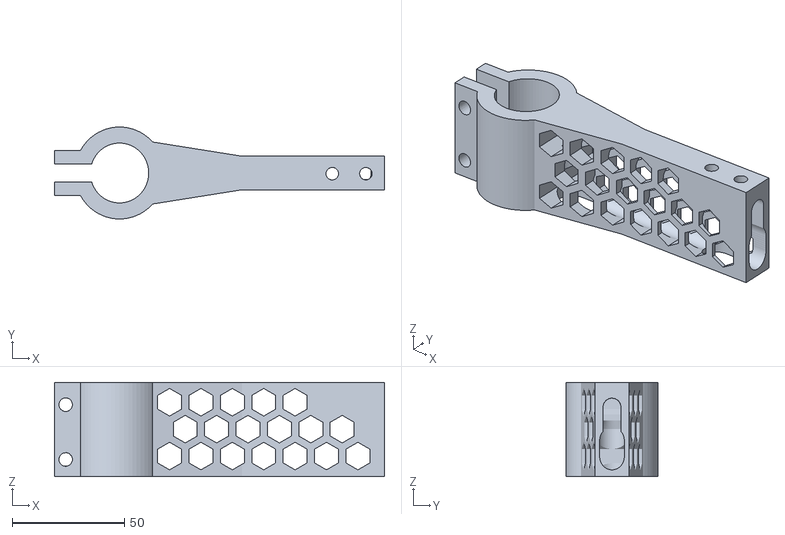
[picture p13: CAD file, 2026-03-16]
CommunityContributions/Misc/SilverBullit/CS7.2 and 7.1 Pole Mount 1in_ModV1.0a.stl
147.2 x 41.1 x 42.0

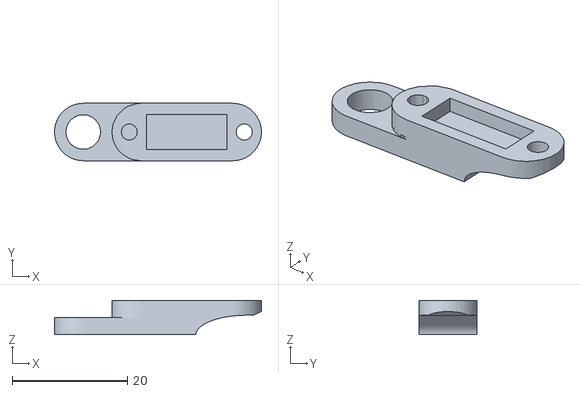
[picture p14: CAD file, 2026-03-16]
CommunityContributions/Misc/SilverBullit/CS7.1 Sorter Homing Bracket_Modified6mmHalfAssHigh.stl
36.0 x 10.0 x 6.00

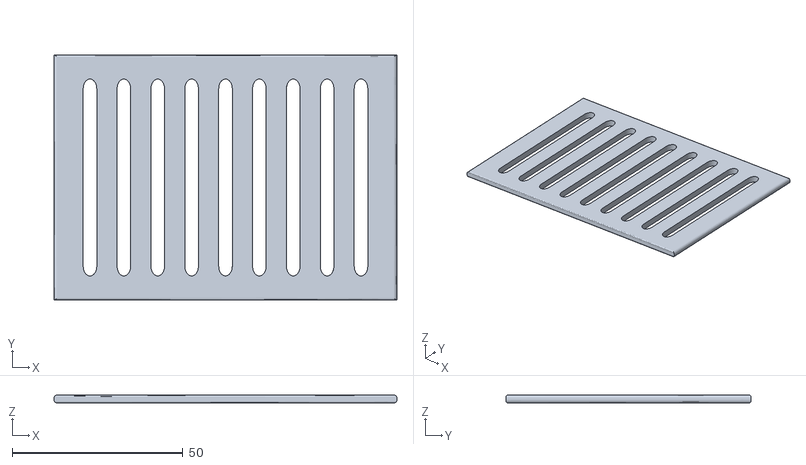
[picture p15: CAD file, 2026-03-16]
CommunityContributions/Misc/SilverBullit/BF556 300 - ElectronicLidModded62,88x64,8.stl
100.4 x 71.8 x 2.40

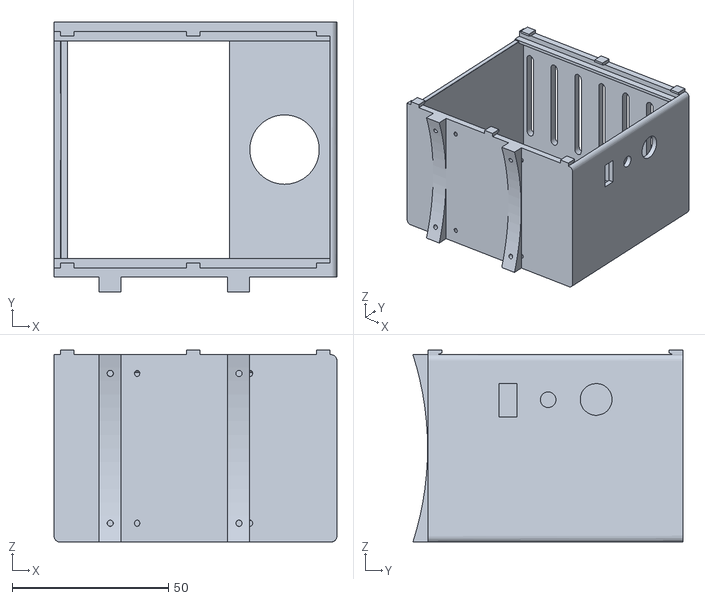
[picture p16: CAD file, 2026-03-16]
CommunityContributions/Misc/SilverBullit/BF556 300 - ElectronicBoxModBLUEforgotsizexsizeHorisontal_BoxV2.stl
90.7 x 86.6 x 61.5

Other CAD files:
CommunityContributions/Misc/SilverBullit/TempBeta_BF556 300 - SJSeths_Offset BracketModV1.0a.stl
CommunityContributions/Misc/SilverBullit/CS7.1 Sorter Pipe Bracket_ElongatedKnob.stl
CommunityContributions/Misc/SilverBullit/CS7.2 and 7.1 Pole Mount 1in_ModV2.0b_Tool-LessKnurledKnobVersion.stl
CommunityContributions/Misc/SilverBullit/BF556 300 - ElectronicLidModded39x74.stl
CommunityContributions/Misc/SilverBullit/BF556 300 - ElectronicBoxModRED52x72Vertical_BoxV2.stl
CommunityContributions/Misc/SilverBullit/BF556 300 - ElectronicBoxModRED52x72Vertical_LidV2.stl
CommunityContributions/Misc/SilverBullit/BF556 300 - ElectronicBoxModded39x74.stl
CommunityContributions/Misc/SilverBullit/BF556 300 - ElectronicLidModRED52x72Vertical_LidV2.stl
CommunityContributions/Misc/SilverBullit/BF556 300 - ElectronicLidModded39,2x74,8.stl
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

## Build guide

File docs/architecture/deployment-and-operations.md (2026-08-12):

# Deployment and Operations

## Baseline and layout

MVP deploys natively on supported 64-bit Raspberry Pi OS for Raspberry Pi 5; containers are not part of MVP. Before pilot, record OS image, kernel, firmware, Node/Python versions, USB adapter identity and appliance build metadata. Installation layout:

```text
/opt/cs71/web/                 SvelteKit production bundle
/opt/cs71/daemon/              Python environment and cs71d
/etc/cs71/cs71d.toml           daemon config, root-owned
/etc/cs71/web.env              web secrets/config, root-owned
/etc/cs71-web/service-token    daemon credential the web service presents, owner-only
/var/lib/cs71d/machine.db      daemon-owned SQLite
/var/lib/cs71-web/web.db       web-owned SQLite
/run/cs71/cs71d.sock           runtime Unix domain socket
```

Use `cs71d` user/group for daemon state and serial device access, `cs71-web` user for SvelteKit, and a narrow `cs71-api` group for socket connection. Caddy runs with its normal service account and reaches SvelteKit on loopback only. Persistent directories are created with installer-defined owner/mode; `/run` is created by systemd runtime-directory support.

## Device identity and services

A udev rule matches the approved USB VID/PID **and serial number** and creates `/dev/cs71` with group access for `cs71d`; it must not match every generic USB serial adapter. Installation verifies the symlink resolves to the intended physical adapter before enabling automatic start.

```mermaid
graph TD
  U[udev stable /dev/cs71] --> D[cs71d.service]
  D --> W[cs71-web.service]
  W --> C[caddy.service]
```

`cs71d.service` is ordered after device availability and local filesystems, owns `/run/cs71`, reads its restricted config, and is restarted on failure with bounded backoff. `cs71-web.service` starts after `cs71d` but tolerates daemon unavailability and retries only at the BFF boundary. Caddy starts after network/loopback web readiness. Service sandboxing follows [security-and-safety.md](security-and-safety.md): separate users, `NoNewPrivileges`, read/write path allow-lists, address-family restrictions, resource limits and explicit serial device access. Verify each setting against pyserial, SQLite and Node behavior rather than assuming a generic hardening profile works.

## Caddy and configuration

Caddy binds the configured LAN HTTPS endpoint and proxies only to `127.0.0.1:<web-port>`. It sets reasonable request/idle timeouts for browser SSE and does not expose `/run/cs71/cs71d.sock`, the daemon API, static secrets or SQLite files. TLS uses the configured local trust/public PKI route; profile policy determines whether development HTTP is permitted.

Daemon config includes fixed device identity/path, serial/protocol limits, bounded queue/event retention, database paths, journal/disk thresholds, supported configuration allow-list, DTR policy and logging level. Web config includes socket path, cookie/TLS origin policy, bootstrap state and rate limits. Config changes are schema-validated, ownership/mode checked, audited and require service restart only where documented. Never accept device paths, executable commands or raw protocol strings from web requests.

## Install, upgrade and rollback

1. Verify signed/reviewed release artifact, manifest, architecture and free disk.
2. Create a consistent backup and record installed version/config checksum.
3. Stop web then daemon writers; retain Caddy maintenance/health behavior as documented.
4. Install versioned artifacts beside the current release; run database migrations and integrity/readiness checks.
5. Start daemon, establish allowed readiness state, then start web and Caddy; smoke test from an authenticated profile.
6. On failure before irreversible migration, stop services, restore the prior artifact/config/database backup, start daemon then web, and record the rollback outcome.

Rollback never assumes an interrupted motion completed. If migration or daemon recovery fails, leave the machine not-ready/`UNCERTAIN`; use the recovery runbook. Upgrade and rollback drills are pilot gates.

## Backups, observability and runbooks

Back up both SQLite stores using consistent SQLite methods, plus config and manifests; encrypt any off-appliance copy. Verify restoration regularly. Backup failure, integrity failure, disk threshold and WAL/checkpoint error are observable and block new daemon state-changing work as defined in [data-and-persistence.md](data-and-persistence.md).

Structured journald logs include UTC timestamp, service/version, severity, `operation_id`, daemon `event_id`, snapshot generation and `X-Request-ID` where available; never log passwords/cookies/secrets. Minimum metrics/health signals: uptime/version, service restart count, controller connection/protocol mode, generation, active operation/fault, reconnect/recovery count, protocol failures, event overflow, queue depth/latency, journal health, backup age and filesystem free space.

Runbooks cover: browser unavailable (verify Caddy/web without touching daemon); daemon unavailable (no claimed machine state); USB loss (`UNCERTAIN`, inspect, explicit recovery); journal/disk failure (stop new motion, preserve evidence, repair/restore); fault recovery; password/admin recovery; restore; upgrade rollback; and emergency response (use physical E-stop/power procedure, not UI stop as substitute). Each runbook gives prerequisites, commands owned by operations, expected evidence and abort conditions.

## Profiles

| Profile | Device/backend | Security/deployment rule | Evidence use |
| --- | --- | --- | --- |
| Development | simulator by explicit config | local HTTP allowed; no physical controller claim | unit/integration UX only |
| Staging | simulator plus controlled Pi smoke | production-like users/services/socket; no production actuation | deployment and regression evidence |
| Production/pilot | approved physical controller | TLS, udev, backups, service hardening and hardware gates required | operator use after gates |

Simulator selection is explicit and conspicuous; production config rejects simulator backend.

## DTR experiment plan — mandatory gate

Linux/POSIX pre-open DTR suppression is **NOT_EXECUTED**. The existing `SerialTransport` explicitly guarantees that pre-open behavior only for pyserial Windows backend; it rejects POSIX/macOS rather than making a physical-reset claim. Before unattended Linux operation, a technician must:

1. identify the exact Pi OS/kernel, USB adapter VID/PID/serial, controller, wiring and instrument setup;
2. measure DTR and reset behavior when opening/closing the port, including daemon restart and client/web crash;
3. repeat idle, representative motion, recovery and USB reconnect cases with motor-energy safeguards;
4. record raw measurements, firmware output, pass/fail criteria and reproducible configuration;
5. decide and document whether a safe qualified open/reset path exists, or install/qualify a hardware motor-enable interlock;
6. obtain safety/release approval and add automated/configuration guardrails for the conclusion.

Until all criteria pass, Linux DTR remains unqualified; no unattended/pilot production claim may use it as a safe pre-reset stop path.

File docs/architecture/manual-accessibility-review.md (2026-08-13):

# Manual Assistive-Technology Review (PI-SWQ-002)

## Why this document exists

`testing-and-quality.md` requires "manual assistive-technology review" as a
pilot entry criterion, and PI-SWQ-002's own fourth bullet asks specifically
for stop/recovery/fault announcements to be documented, with any
remediation, before pilot. This is deliberately **not** something automated
tooling can close: `checkAccessibility` (`appliance/web/src/routes/
accessibility.ts`, PI-SWQ-002) runs axe-core against a layout-less jsdom
document and cannot evaluate whether a screen reader actually announces a
state change at the right moment, in the right words, without being
buried by unrelated chatter - that is a claim only a person operating real
assistive technology can make. This document is the template that review
fills in, not a substitute for having run it. Until a reviewer completes it,
the checklist below stays unchecked, the same "template, not a claim" rule
this project already applies to HIL/DTR/pilot evidence.

## What to check

This project uses exactly two live-region roles throughout, deliberately
not more: `role="alert"` for something that went wrong (an assertive
announcement, interrupting), and `role="status"` for something that
succeeded or is informational (a polite announcement, queued behind
whatever the screen reader is already saying). Every one of them in the
current codebase is listed below, grouped by page. A reviewer's job is to
reach the state that shows each one, using only the assistive technology
and input method named in the session record, and confirm it is announced,
once, in comprehensible words, without duplicating or drowning out another
announcement already in flight.

### Dashboard (`/`) - the highest-priority surface

| Component | Role | Field | Trigger |
| --- | --- | --- | --- |
| `StopControl` | `alert` | `stop-error` | A software stop is refused or fails |
| `StopControl` | `status` | `stop-accepted` | A software stop is accepted |
| `MachineStatus` | `alert` | (unavailable) | The daemon stops answering |
| `MachineStatus` | `status` | (uncertain) | The machine's state is `UNCERTAIN` |
| `RecoveryControl` | `alert` | `recovery-error` | Recovery is refused or fails |
| `RecoveryControl` | `status` | `recovery-accepted` | Recovery is accepted |
| `ManualControls` | `alert` | `command-error` | Connect/home/sort/feed is refused or fails |
| `ManualControls` | `status` | `command-accepted` | Connect/home/sort/feed is accepted |

### `/dataset`, `/routing`, `/system`, `/operations` - secondary surfaces

| Page | Role | Field | Trigger |
| --- | --- | --- | --- |
| `/dataset` | `alert`/`status` | `train-error`/`train-status` | Training triggered/refused |
| `/dataset` | `alert`/`status` | `activate-error`/`activate-status` | Candidate activated/refused |
| `/dataset` | `alert`/`status` | `rollback-error`/`rollback-status` | Rollback performed/refused |
| `/dataset` | `alert`/`status` | `autonomy-review-error`/`-status` | An autonomous attempt reviewed/refused |
| `/routing` | `alert`/`status` | `routing-start-error`/`-status` | A routing run started/refused |
| `/routing` | `alert`/`status` | `routing-stop-error`/`-status` | A routing run stopped/refused |
| `/system`, `/operations`, `/dataset`, `/routing` | `alert` | (unavailable) | The relevant service stops answering |

### `/login`

| Role | Trigger |
| --- | --- |
| `status` | A notice such as "your session ended" is shown |
| `alert` | A failed sign-in attempt |

## Session record

Fill in one row per reviewer session. A single pass with one screen reader
and one keyboard is not sufficient to close this checklist - the pilot
entry criterion is a genuine sample, not one data point.

| Date | Reviewer | Assistive technology + version | Browser | Input method | Pages covered |
| --- | --- | --- | --- | --- | --- |
| _(unfilled)_ | | | | | |

## Findings

For each row in the tables above, record: announced as expected / announced
but wrong wording or timing / not announced / not reached this session.

| Component/page | Field | Result | Notes |
| --- | --- | --- | --- |
| _(unfilled - populate from the tables above during the review session)_ | | | |

## Remediation

Any finding other than "announced as expected" gets a row here, and stays
open until re-verified by a follow-up session, not closed by the same
reviewer's own guess that a fix worked.

| Finding | Owner | Fix | Re-verified (date, reviewer) |
| --- | --- | --- | --- |
| _(unfilled)_ | | | |

## Sign-off

This review is **not complete**, and this document does not represent
completed pilot-entry evidence, until every row above the sign-off line has
a real reviewer, a real session, and every remediation is re-verified.

- [ ] At least one full session completed with a screen reader (NVDA, JAWS, or VoiceOver).
- [ ] At least one full session completed keyboard-only, no pointer device, no assistive technology beyond the OS's own focus indication.
- [ ] Every row in "What to check" has a recorded finding.
- [ ] Every remediation row is re-verified.

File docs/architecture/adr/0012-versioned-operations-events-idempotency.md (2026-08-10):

# ADR-0012: Versioned operations, events and idempotency

**Status:** Accepted<br>
**Date:** 2026-08-10

## Context

Retrying network/BFF requests and reconnecting event streams must not duplicate machine intent or confuse firmware protocol correlation.

## Decision

Expose versioned `/v1` operations with UUID `operation_id`, daemon `event_id`, snapshot generation, finite deadlines and idempotency keys. Keep all separate from protocol `request_id`.

## Options considered

| Option | Reason selected or rejected |
| --- | --- |
| Durable operations/events/idempotency | Selected: makes retries and audit explicit. |
| Fire-and-forget commands | Rejected: no trustworthy lifecycle or deduplication. |
| Use protocol request_id as API ID | Rejected: session-scoped/wrapping wire correlation. |

## Consequences

### Positive

- Client can query durable outcome and reconcile SSE loss.
- Stale UI commands are rejected before serial I/O.

### Negative

- Requires retention/pruning and canonical request fingerprints.

## Implementation constraints

- Success requires trusted terminal; 202 is acceptance only.
- Stale event cursor emits snapshot-required rather than silent loss.

## Validation and revisit triggers

- Test duplicate keys, conflicting keys, deadlines, stale generations, overflow and request-id wrap.
- Revisit for a new API major or retention scale requirement, preserving ID separation.

## Links

- [API](../api-and-events.md); [Runtime](../runtime-and-domain.md); [PI-DOMAIN-001](../backlog.md#pi-domain-001--implement-operations-idempotency-and-snapshot-generation).

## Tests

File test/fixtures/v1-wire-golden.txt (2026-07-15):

# CS7.1 firmware 7.1.260714.6 legacy wire baseline
#
# Bytes are represented with C escapes. Requests exclude transport timing.
# Responses are exact: spaces, case, spelling, JSON order, and LF are normative.

[startup]
request=<reset>
response=Ready\n

[inspection]
request=ping\n
response=\x20ok\n
request=version\n
response=7.1.260714.6\n
request=getconfig\n
response={"FeedMotorSpeed":90,"FeedCycleSteps":70,"SortMotorSpeed":90,"SortSteps":20,"NotificationDelay":90,"SlotDropDelay":400,"AirDropEnabled":0,"AirDropPostDelay":0,"AirDropPreDelay":30,"AirDropSignalTime":50,"FeedHomingOffset":3,"SortHomingOffset":0,"AutoMotorStandbyTimeout":60,"DebounceTimeout":300,"DebouncePauseTime":500}\n

[negotiation-on-old-firmware]
request=protocol:2?\n
response=ok\n
request=protocol:2\n
response=ok\n

[framing]
request=\n
response=ok\n
request=ping\r\n
response=\x20ok\n
request=<41 printable bytes>\n
response=error:command too long\n
request=pi\x00ng\n
response=error:invalid command\n

[setters-valid]
request=feedspeed:90\n
response=ok\n
request=feedsteps:70\n
response=ok\n
request=feedhomingoffset:3\n
response=ok\n
request=sortspeed:90\n
response=ok\n
request=sortsteps:20\n
response=ok\n
request=sorthomingoffset:0\n
response=ok\n
request=slotcount:8\n
response=ok\n
request=notificationdelay:90\n
response=ok\n
request=slotdropdelay:400\n
response=ok\n
request=automotorstandbytimeout:60\n
response=ok\n
request=debounceTimeout:300\n
response=ok\n
request=debounceTime:500\n
response=ok\n
request=airdropenabled:false\n
response=ok\n
request=airdroppredelay:30\n
response=ok\n
request=airdroppostdelay:0\n
response=ok\n
request=airdropdsignalduration:50\n
response=ok\n
request=cameraledlevel:78\n
response=ok\n

[setters-invalid]
request=feedspeed:0\n
response=error:invalid feedspeed\n
request=feedsteps:1001\n
response=error:invalid feedsteps\n
request=feedhomingoffset:201\n
response=error:invalid feedhomingoffset\n
request=sortspeed:101\n
response=error:invalid sortspeed\n
request=sortsteps:0\n
response=error:invalid sortsteps\n
request=sorthomingoffset:201\n
response=error:invalid sorthomingoffset\n
request=slotcount:0\n
response=error:invalid slotcount\n
request=notificationdelay:-1\n
response=error:invalid notificationdelay\n
request=slotdropdelay:-1\n
response=error:invalid slotdropdelay\n
request=automotorstandbytimeout:4294968\n
response=error:invalid automotorstandbytimeout\n
request=debounceTimeout:-1\n
response=error:invalid debounceTimeout\n
request=debounceTime:-1\n
response=error:invalid debounceTime\n
request=airdropenabled:yes\n
response=error:invalid airdropenabled\n
request=airdroppredelay:-1\n
response=error:invalid airdroppredelay\n
request=airdroppostdelay:-1\n
response=error:invalid airdroppostdelay\n
request=airdropdsignalduration:-1\n
response=error:invalid airdropdsignalduration\n
request=cameraledlevel:not-a-number\n
response=error:invalid cameraledlevel\n

[commands]
precondition=running
request=homefeeder\n
response=ok\n
request=homesorter\n
response=ok\n
request=sortto:3\n
response=ok\n
request=test:1\n
response=testing started\n
request=sorttest:1\n
response=testing started\n
request=stop\n
response=stopped\n

[commands-invalid]
request=3x\n
response=error:invalid slot\n
request=xf:3x\n
response=error:invalid xf\n
request=sortto:3x\n
response=error:invalid sortto\n
request=test:-1\n
response=error:invalid test\n
request=sorttest:-1\n
response=error:invalid sorttest\n
request=unknown\n
response=ok\n

[state-and-queue]
precondition=not-homed
request=3\n
response=error:not homed\n
precondition=busy-with-one-pending-command
request=version\n
response=error:busy\n
precondition=running,queue=(0,0)
request=1\n
response=<none until physical feed completion>,done\n
postcondition=queue=(0,1)
request=1\n
response=<none until physical feed completion>,done\n
postcondition=queue=(1,1)

[progress-and-fault]
precondition=feed-request-waiting-for-material
response=waiting for brass\n
maximum-rate=1 line per second
precondition=feed-home-search-exceeds-threshold
response=error:feed overtravel detected\n

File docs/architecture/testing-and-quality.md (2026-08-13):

# Testing and Quality

## Evidence policy

A simulator validates only its declared contract. It may satisfy unit, integration, UI and controlled stress cases, but **never** DTR, USB electrical behavior, physical motion/completion, stop latency, sensor, reboot-under-motion or hardware release gates. Reports label backend, fixture/version, device identity (for HIL), test data and result type. A test does not turn an unmeasured target into a result.

## Test pyramid and matrix

| Layer | Primary evidence | Required examples |
| --- | --- | --- |
| Unit/property | pure Python/TypeScript | domain transitions, idempotency fingerprinting, generation monotonicity, parser bounds, RBAC/CSRF helpers |
| Protocol parity | existing `cs71_protocol` fixtures plus transcripts | v1 discovery, v2 activation, CRC boundaries, request/event tracking, exact terminals and recovery |
| Daemon integration | deterministic simulator | serial ownership, queue bounds, stop preemption, journal errors, reconnect, SSE overflow |
| API/contract | OpenAPI/client tests | schema/error mapping, compatibility, headers, SSE resume/snapshot-required |
| BFF/browser | SSR and browser tests | auth/session/CSRF, role routes, no optimistic completion, a11y keyboard/screen reader checks |
| Pi resource/deploy | controlled Pi profile | service restart isolation, memory/CPU/disk thresholds, udev/install/backup/restore |
| HIL | selected physical rig | DTR, real serial parity, homing/sort/stop/fault/USB/power recovery |

## Simulator and protocol contract

The deterministic simulator implements only documented firmware behavior needed by tests, uses injected clock/scheduling (no test sleeps), seedable scenarios and golden transcript replay. It models startup, v1/v2 negotiation, optional CRC, accepted/progress/terminal responses, events, configurable timing, faults, disconnects, malformed frames, event gaps and stop. It is selected by explicit development/test configuration and is refused by production profile validation. Simulator changes require comparison against normative protocol fixtures; they do not reinterpret ambiguous firmware behavior.

Protocol parity tests import/use the real `cs71_protocol` public boundary, including `ProtocolClient`, typed models and scripted transport. Daemon tests must prove no alternate serial-opening/parsing path exists. Fuzz/property tests cover line framing bounds, unexpected response/event order, sequence gaps, request-id wrapping, duplicate idempotency requests, stale generations and scheduler invariants. Stress tests force slow SSE consumers, normal-lane saturation, repeated reconnect and concurrent BFF calls while asserting bounded memory and no duplicate operation execution.

The versioned Raspberry Pi 5 software profile measures NFR-01 and NFR-02
without a controller. It records Pi model, OS/kernel, CPU governor, process
versions, load generator, sample count and percentile method. Priority-stop
admission must be reported within 250 ms, excluding firmware and physical stop
time. At least 99% of internal snapshot reads must complete within 100 ms.
Failure blocks software qualification; simulator or desktop measurements cannot
replace this Pi profile. `appliance/daemon/scripts/measure_nfr.py`
(PI-SWQ-001) implements load profile v1 and runs in CI on every push, but a
GitHub-hosted runner is never the approved rig, so its own report always
stamps `evidence_status: NOT_EXECUTED`; re-running the identical script on
the approved Raspberry Pi 5 is what actually closes this gate, the same
"NOT_EXECUTED is not performed, not failed" posture SAF-07 already uses for
the Linux DTR gate.

## Browser, accessibility and security

Browser tests run server-rendered flows with JavaScript disabled where supported and enabled for SSE behavior. They cover login/logout/session expiration, CSRF rejection, each RBAC denial/allowance, stale UI command rejection, stop visibility, `UNCERTAIN` prominence, event overflow resync and daemon/web restart isolation. Accessibility checks include semantic forms, keyboard-only stop/recovery flows, focus management, contrast and announced state/fault changes. Automated WCAG 2.1/2.2 A/AA checks (PI-SWQ-002, `appliance/web/src/routes/accessibility.ts`) run axe-core against every MVP page's own rendered HTML inside an isolated jsdom window per check; rendering-dependent rules such as `color-contrast` report incomplete rather than pass/fail, since jsdom computes no CSS layout. Manual assistive-technology review is a pilot entry criterion, using [`manual-accessibility-review.md`](manual-accessibility-review.md)'s template - a document to fill in with a real reviewer session, not evidence in itself until someone has. Security tests include auth/session fixation, CSRF, request-size/rate limits, socket non-exposure, secret redaction and dependency audit review.

## HIL cases and evidence

HIL procedures have fixture revision, technician, safeguards, controller/adapter identity, firmware build, Pi image, instrument settings, raw results and pass/fail threshold. Required cases include: device identity; real v1/v2/CRC parity; DTR open/reset measurements; home/sort trusted terminals versus observed behavior; priority software-stop response and physical behavior; fault injection; USB loss; daemon restart; web restart during daemon operation; power/reboot recovery; storage/journal fault response; and soak under defined load. Software stop is tested as software behavior and never certified as E-stop.

## CI and release gates

Every PR runs formatting/lint/type checks already present for touched workspace, unit tests, protocol fixtures, contract compatibility, generated-client drift, relevant browser tests and docs/link checks. Mainline additionally runs deterministic integration/stress and dependency/license/security review jobs available in the repository/toolchain. Hardware evidence is stored/referenced separately and gated manually: no CI simulator success can mark it passed. Releases require clean build provenance, migration/rollback and backup/restore evidence, all software gates, approved HIL evidence, closed DTR gate and runbook drill.

Flakes are quarantined only with issue, owner, reproducible evidence and expiry; quarantined tests do not count as passed release evidence. Test data is synthetic or approved fixture data, versioned where practical, minimal, and contains no secrets or operator credentials.

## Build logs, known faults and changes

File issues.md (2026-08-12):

# CS7.1 Firmware Improvement Plan

This roadmap covers `ArduinoCode/CS71_Arduino/CS71_Arduino.ino` version
`7.1.260131.1`. The goal is to improve correctness, stop responsiveness,
maintainability, and testability without breaking the Arduino Uno hardware,
the Arduino IDE workflow, or the serial contract used by AI Sorter software
1.1.46 and newer.

**Implementation status:** the software work is implemented through firmware
`7.1.260714.6`. Current software evidence includes 89 native tests, 49 native-v2
tests, 116 host tests, 317 daemon/simulator tests, 508 appliance web tests,
and 59 appliance ops artifact tests. Unchecked criteria below
require an Arduino IDE run, physical hardware, long-duration testing, a logic
analyzer, or the Windows application; they are not being represented as
complete.

## Active Raspberry Pi appliance issues

Canonical dependencies and acceptance criteria are maintained in
[`docs/architecture/backlog.md`](docs/architecture/backlog.md); milestone order
is maintained in [`docs/architecture/roadmap.md`](docs/architecture/roadmap.md).

- [x] PI-SIM-001/002: deterministic simulator, adverse scenarios, and strict
      v1/v2 fixture replay.
- [x] PI-DAEMON-001 prerequisite: `ProtocolClient` supports deadline-preserving
      interrupt polling and trusted same-owner out-of-band stop.
- [x] PI-DAEMON-001: implement the sole serial worker, bounded normal admission,
      coalesced priority-stop lane, and single-open/concurrency evidence.
- [x] PI-DAEMON-002: publish session states and conservative reconnect without
      command replay. Real POSIX serial opening stays blocked by the
      unqualified DTR gate.
- [x] PI-DOMAIN-001: implement durable operations, idempotent admission and
      snapshot generation. The deferred terminal-mismatch daemon-result
      assertion is closed: an unverified terminal makes the operation
      `UNCERTAIN`.
- [x] PI-DOMAIN-002: make journal failure and priority stop fail closed. A
      refused journal write latches the machine undurable and blocks new
      motion with `JOURNAL_UNAVAILABLE`; a stop without its trusted terminal
      leaves affected work `UNCERTAIN`.
- [x] PI-DOMAIN-003: typed home and sort adapters validate advertised
      capability, slot range and sorter position before any serial I/O. Feed
      returns `UNSUPPORTED`; its lifecycle stays blocked on V2-09 and hardware
      evidence.
- [x] PI-DOMAIN-004: session and configuration operations. Connect and
      recover repair an unready session; configuration is validated, journaled
      and versioned, and never reaches the controller.
- [x] PI-API-001: internal HTTP/JSON API over the Unix domain socket, with
      no TCP path, a protected service credential, contract-checked responses
      and `cs71d --serve`.
- [x] PI-API-002: resumable bounded SSE event stream. Retention is in
      memory; durable replay across a restart is not implemented.

## Constraints that apply to every phase

- `ArduinoCode/CS71_Arduino/CS71_Arduino.ino` remains the canonical firmware
  and must remain directly openable, verifiable, and uploadable in Arduino IDE.
- Preserve the current Uno/CNC-shield pin mapping and 16-microstep defaults
  unless a task explicitly changes the hardware configuration.
- Treat serial command names, response text, line framing, and response timing
  as an external API. Intentional protocol changes require a firmware version
  bump, documentation, and compatibility verification with the Windows
  application.
- Store fixed serial strings with `F("...")` to protect the Uno's 2 KB SRAM.
- Native tests cover parsing, calculations, and state transitions. Motor
  direction, homing, sensor polarity, stop latency, and signal timing still
  require bench testing on representative hardware.
- Complete and validate one phase before starting a dependent phase. Do not
  combine the parser rewrite, stop redesign, and timer refactor into one patch.

## Phase 0 — Record a behavioral baseline

**Priority:** Required first

Before changing behavior, record what the current firmware and hardware do.
This gives later phases a concrete regression target instead of relying on
comments or assumptions.

### Tasks

1. Verify the unmodified sketch for an Arduino Uno in Arduino IDE.
2. Flash a bench unit with the default configuration and record:
   - startup output;
   - `version`, `getconfig`, and `ping` output byte-for-byte;
   - immediate and eventual responses to `sortto:1`, `homefeeder`,
     `homesorter`, one numeric slot command, and `xf:0`;
   - feed/sort motor direction and successful homing;
   - default `FEED_DONE_SIGNAL` timing with AirDrop disabled.
3. Repeat the relevant timing capture with `AIR_DROP_ENABLED=true` if AirDrop
   hardware is available.
4. Document the Serial Monitor settings: 9600 baud and newline-terminated
   commands.
5. Save the observations in the existing firmware documentation or a compact
   checked-in test fixture. Do not commit machine-specific COM-port names.

### Acceptance criteria

- [ ] The current sketch verifies for Arduino Uno before refactoring begins.
- [ ] Exact baseline responses exist for startup, diagnostics, configuration,
      homing, direct sort, forced feed, and a normal queued feed/sort cycle.
- [ ] Bench notes identify which checks require sensors, motors, or AirDrop.
- [ ] Any mismatch between documentation and observed firmware behavior is
      recorded before deciding which behavior is authoritative.

---

## Phase 1 — Apply isolated correctness and cleanup fixes

**Priority:** High  
**Depends on:** Phase 0

These changes are small enough to review and bench-test independently. Make
them as separate commits so a regression can be bisected.

### 1.1 Clamp camera PWM correctly

**Problem:** `adjustCameraLED()` evaluates and discards the upper-bound ternary,
so values above 255 wrap when passed to AVR `analogWrite()`.

**Implementation:**

```cpp
int clampByte(int value) {
  if (value < 0) return 0;
  if (value > 255) return 255;
  return value;
}

void adjustCameraLED(int level) {
  cameraLEDLevel = clampByte(level);
  analogWrite(CAMERA_LED_PWM, cameraLEDLevel);
}
```

Keep `clampByte()` independent of Arduino APIs so it can move into the native
logic module in Phase 2.

**Acceptance criteria:**

- [x] Native boundary tests verify values `-10`, `0`, `128`, `255`, and
      `300` result in effective levels `0`, `0`, `128`, `255`, and `255`.
- [ ] `getconfig` reports the clamped `CameraLEDLevel` when PWM support is
      compiled in.
- [ ] The non-PWM default hardware configuration is unchanged.

### 1.2 Make motor-standby parsing and arithmetic explicit

**Problem:** `autoMotorStandbyTimeout` is a signed `long`, but its setter uses
`String::toDouble()`. Multiplication by 1000 can overflow before comparison
with the `millis()` delta.

**Implementation:**

1. Define an explicit maximum timeout in seconds that can safely be converted
   to milliseconds on AVR.
2. Parse only a complete non-negative integer; do not accept a numeric prefix
   followed by arbitrary text.
3. Store the timeout as `unsigned long`.
4. Reject out-of-range input with an `error:` response instead of truncating or
   wrapping.
5. Keep the existing rollover-safe subtraction form:

```cpp
if (millis() - timeSinceLastMotorMove >= standbyTimeoutMs) {
  // ...
}
```

**Acceptance criteria:**

- [ ] `automotorstandbytimeout:0` disables standby.
- [ ] `automotorstandbytimeout:60` behaves as before.
- [x] Negative, fractional, malformed, and overflowing values return `error:`
      and leave the previous setting unchanged.
- [x] The maximum accepted value converts to milliseconds without overflow.
- [x] Behavior remains correct across a simulated `millis()` rollover.

### 1.3 Name sorter homing limits

Replace the unexplained `200` and `210` full-step limits with constants such as
`SORT_FULL_REVOLUTION_STEPS` and `SORT_HOMING_MARGIN_STEPS`. Keep the resulting
microstep counts exactly equal to the current values.

**Acceptance criteria:**

- [x] Generated search limits are unchanged for the default configuration.
- [x] The margin comment explains its hardware purpose rather than restating
      the arithmetic.

### 1.4 Remove genuinely dead code

- Remove empty `serialMessenger()` and its call from `loop()`.
- Keep `FreeMem()` temporarily for memory measurements in Phases 2 and 3.
- If `FreeMem()` becomes a public diagnostic, expose it through a separate
  `freemem` command rather than changing the existing `getconfig` schema.

**Acceptance criteria:**

- [ ] Removing `serialMessenger()` produces no serial or motor behavior change.
- [x] `FreeMem()` remains internal; no new serial response or `getconfig`
      property was added.

---

## Phase 2 — Add an optional host-test and compile workflow

**Priority:** High  
**Depends on:** Phase 1

Testing infrastructure must supplement, not replace, the documented Arduino
IDE workflow.

### Tasks

1. Add `platformio.ini` with:
   - an Arduino Uno environment that compiles the canonical sketch; and
   - a `native` environment that builds only platform-independent logic and
     tests.
2. Configure PlatformIO to use `ArduinoCode/CS71_Arduino` as the firmware source
   without moving or renaming `CS71_Arduino.ino`.
3. Add `logic.h/.cpp` beside the sketch for functions that do not call Arduino
   APIs. Start with:
   - byte clamping;
   - speed conversion;
   - checked integer parsing;
   - timeout conversion and elapsed-time checks;
   - homing-limit calculations.
4. Add Unity tests under `test/`. Do not add ArduinoFake until a test actually
   needs an Arduino API; prefer dependency-free logic.
5. Add CI jobs for native tests and Uno compilation.
6. Document both workflows:

```sh
pio run -e uno
pio test -e native
pio test -e native -f test_logic
```

Arduino IDE Verify/Upload remains the supported path for builders who do not
use PlatformIO.

### Acceptance criteria

- [x] `pio run -e uno` compiles the canonical sketch in place.
- [ ] Arduino IDE still opens and verifies the sketch without generated files,
      symlinks, or manual source copying.
- [x] `pio test -e native` runs without an attached board.
- [x] A single suite can be run with `pio test -e native -f <suite>`.
- [x] CI runs native tests and Uno compilation on every firmware change.
- [x] Compiled flash and SRAM usage are reported so later refactors cannot
      silently exceed Uno limits.

---

## Phase 3 — Replace `String` command accumulation with a bounded parser

**Priority:** High  
**Depends on:** Phase 2

### Problems to solve

- `String input` grows without a length limit if no newline arrives.
- Repeated dynamic allocation is undesirable on a long-running 2 KB SRAM
  device.
- `delay(1)` is executed for every received byte.
- Prefix parsing through `startsWith()`, `replace()`, `toInt()`, and
  `toDouble()` accepts malformed values too easily.

### Design

1. Use a fixed receive buffer sized for the longest documented command plus
   terminator.
2. Consume serial bytes without `delay(1)`.
3. Accept `\n` as the frame terminator and ignore a single preceding `\r` so
   both newline and CRLF terminals work.
4. If the line exceeds the buffer:
   - mark the frame as overflowed;
   - discard bytes through the next newline;
   - return `error:command too long`;
   - never dispatch the truncated prefix.
5. Parse command name and value without modifying the receive buffer.
6. Require complete, range-checked integer or boolean values. Reject trailing
   garbage and preserve the previous setting on error.
7. Preserve the exact existing spellings, including mixed-case
   `debounceTimeout:`/`debounceTime:` and legacy
   `airdropdsignalduration:`.
8. Preserve current successful responses, including the leading space in the
   legacy `ping` response, unless an application compatibility test authorizes
   a protocol change.
9. Characterize the current unknown-command `ok` response in Phase 0. Preserve
   it for compatibility or change it only with a documented protocol/version
   decision.

### Tests

- Every currently supported command.
- Empty line, CRLF, partial command split across reads, and multiple complete
  lines arriving in one UART burst.
- Exactly-full buffer, one-byte overflow, long overflow, and recovery on the
  next valid line.
- Missing newline without memory growth.
- Negative, maximum, overflowing, fractional, and malformed numeric values.
- Boolean values accepted by the current protocol.
- Repeated command streams with stable `FreeMem()` on a bench unit.

### Acceptance criteria

- [x] No dynamic `String` object is used by command reception or dispatch.
- [x] No per-byte `delay()` remains.
- [x] A truncated command can never execute.
- [ ] Valid command behavior and responses match the Phase 0 fixtures.
- [x] Invalid values return a deterministic `error:` response and do not
      partially update runtime state.
- [ ] Native parser tests pass and an extended bench command stream shows no
      declining free-memory trend.

---

## Phase 4 — Define and implement a real stop state

**Priority:** High for machine control; do not call it an emergency stop  
**Depends on:** Phase 3

Software `stop` improves responsiveness but is not a substitute for removing
power with a physical emergency-stop circuit. Document that distinction.

### Protocol and state decisions

Before implementation, define and document:

1. The exact successful response (`stopped` is preferred over success-shaped
   `done`).
2. Whether an already queued non-stop command is rejected, retained, or
   discarded when stopping.
3. Which commands are allowed while stopped.
4. How position is recovered after interrupting a motor between steps.

Recommended behavior:

- Serial reception runs every loop iteration, including while motors move.
- A complete `stop` frame has priority over ordinary command dispatch.
- At most one ordinary command may be pending while busy. Additional ordinary
  commands receive `error:busy`; their bytes must not be appended to an
  existing frame.
- Outside the known blocking sections listed in Phase 5, `stop` disables motor
  drivers immediately after the current step pulse, cancels feed/sort/test
  state, clears pending movement, and marks both axis positions unknown.
- During a remaining blocking `delay()`, incoming bytes stay in the UART buffer
  and cannot be processed until the delay returns. Measure and document this
  temporary worst-case latency; Phase 5 removes it.
- Movement and feed commands remain rejected until both axes complete an
  explicit recovery home. Diagnostic commands such as `version`, `getconfig`,
  and `ping` remain available.
- Successful recovery resets sorter queue positions consistently before normal
  operation resumes.

### Implementation tasks

1. Introduce an explicit top-level mode such as `Running`, `Stopped`, and
   `Recovering`; do not represent stop behavior only by manipulating a loose
   subset of booleans.
2. Centralize cancellation in `enterStoppedState()`.
3. In that function:
   - disable `MOTOR_Enable`;
   - clear feed scheduling, movement, homing, completion, and error state;
   - clear sorter movement, homing, and completion state;
   - cancel test cycles and pending completion signals;
   - force `FEED_DONE_SIGNAL` low;
   - invalidate feed and sorter positions.
4. Add a controlled recovery path that homes each axis and only then returns
   to `Running`.
5. Ensure an interrupted cycle cannot fall through `onFeedComplete()` and emit
   `done`.

### Acceptance criteria

- [ ] Outside the blocking sections listed in Phase 5, `stop` suppresses
      further step pulses after at most the current pulse plus one loop
      iteration.
- [ ] `MOTOR_Enable` is driven to its disabled state and
      `FEED_DONE_SIGNAL` is low.
- [ ] Stop during feed stepping, sort stepping, homing stepping, and test
      movement ends in the same explicit stopped state.
- [x] Phase 5 removed all runtime millisecond blocking sections; only individual
      motor-step `delayMicroseconds()` calls remain.
- [x] Native state tests and control-flow checks suppress stale `done` after
      cancellation.
- [x] Normal movement is rejected until position recovery completes.
- [ ] Recovery homes both axes, resets the sorter queue, and permits the next
      normal cycle.
- [ ] Native state tests and physical bench tests cover each interruption
      point.
- [x] Documentation states that software stop is not a certified emergency
      stop.

---

## Phase 5 — Remove long blocking operations incrementally

**Priority:** Medium  
**Depends on:** Phase 4

The current blocking inventory is broader than the two most visible delays:

- `delay(1)` in serial reception (removed in Phase 3);
- `delay(40)` in sorter test mode;
- `delay(slotDelayCalc)` before sorter movement;
- AirDrop pre-delay and signal duration;
- feed-completion notification delay;
- `delay(debounceTime)` while settling a detected case;
- the synchronous step loop in `jogSorter()`;
- per-step `delayMicroseconds()` calls.

Keep the step-pulse delays for now: they define pulse width and motor speed.
Their maximum duration becomes the expected upper bound for stop latency.
Convert the other blocking operations one subsystem at a time.

### 5.1 Slot-drop gate

Replace `delay(slotDelayCalc)` with explicit `Idle`/`WaitingDropClearance`
states. Do not update `qPos1`/`qPos2` or begin movement until the timer expires.

### 5.2 Feed completion and AirDrop

Represent completion as:

`Idle → PreSignalDelay → SignalHigh → NotificationDelay → Notify → Idle`

Set `FEED_DONE_SIGNAL` low on every cancellation and error path.

### 5.3 Sensor debounce settling

Replace `delay(debounceTime)` with a settling state and deadline. Continue
polling serial input and stop state while settling. Define whether the
proximity sensor must remain active for the entire settling period.

### 5.4 Test pacing and sorter jog

- Replace test-mode `delay(40)` with a scheduled next-action timestamp.
- Convert `jogSorter()` into an explicit movement/homing phase so startup and
  `homesorter` remain interruptible after serial initialization.

### Timing rules

- Use rollover-safe checks of the form
  `static_cast<unsigned long>(now - started) >= duration`.
- Capture `now = millis()` once per loop pass and pass it to timer updates.
- Do not promise impossible exact timing. Define tolerances from measured loop
  jitter and verify physical outputs with a logic analyzer.

### Acceptance criteria

- [x] No `delay()` remains in the runtime path.
- [x] Remaining `delayMicroseconds()` calls are limited to documented step
      pulse generation.
- [x] Serial reception and `stop` are serviced cooperatively in every software
      waiting state.
- [ ] Slot-drop, debounce, notification, and AirDrop durations remain within
      the measured and documented tolerance established on the bench.
- [ ] AirDrop produces one pulse of the configured duration and always returns
      low.
- [ ] Existing queued-sort behavior is unchanged.
- [x] Each converted subsystem has native fake-time tests before the next
      subsystem is changed.

---

## Phase 6 — Make diagnostic slot ranges explicit

**Priority:** Low  
**Depends on:** Phases 3 and 5

### Problem

`test:` previously used `random(0,6)` (slots 0–5), while `sorttest:` used
`random(0,8)` (slots 0–7). The upper bound of Arduino `random(min,max)` is
exclusive. Neither range was linked to an explicit firmware slot count, and
`SORTER_CHUTE_SEPERATION` describes distance between slots, not slot count.

### Implementation

1. Added independent `SORTER_SLOT_COUNT` and runtime `slotCount`, defaulting to
   8.
2. Added the exact checked `slotcount:` setter for manual or advanced
   configuration. It cross-validates with `sortsteps:` against AVR 16-bit
   movement arithmetic.
3. Deliberately kept `SlotCount` out of `getconfig`; Windows application
   tolerance for additional JSON properties has not been verified.
4. Both diagnostic modes now use `[0, slotCount)`.
5. Documented that slot count and mechanically compatible chute spacing are
   independent.

This intentionally expands the default feed/sort diagnostic from slots 0–5 to
0–7. Treat that as a documented behavior correction, not as “no behavior
change.”

### Acceptance criteria

- [x] Both diagnostic modes select only values in `[0, slotCount)`.
- [x] Default diagnostics can reach all eight standard slots.
- [x] Slot count and chute separation remain independent settings.
- [x] Invalid values (`0`, negative, or above the AVR-safe limit for the
      current geometry) are rejected without changing the active value.
- [x] The `getconfig` schema remains unchanged pending application
      compatibility verification.

Native logic tests and an Uno compile cover the arithmetic and build. Physical
slot reachability, motor direction, homing, and application-driven advanced
configuration still require hardware/application validation.

---

## Phase 7 — Documentation, compatibility, and release

**Priority:** Required for completion  
**Depends on:** All implemented phases

### Tasks

1. Update `FIRMWARE_VERSION` and the version banner together whenever protocol
   behavior or required AI Sorter compatibility changes.
2. Update firmware documentation with:
   - Arduino IDE compile/upload instructions;
   - PlatformIO build and native-test commands;
   - how to run one test suite;
   - exact serial commands and responses;
   - stopped/recovery behavior;
   - configurable limits and defaults;
   - the distinction between software stop and physical power isolation.
3. Keep community firmware variants unchanged unless their maintainers
   explicitly opt into the canonical changes.
4. Run the full native suite, Uno compile, flash/boot smoke test, and the Phase
   0 bench matrix.
5. Compare flash/SRAM usage with the baseline and investigate material growth.

### Release acceptance criteria

- [x] PlatformIO compiles the canonical Uno firmware; Arduino IDE verification
      remains a manual release check.
- [x] Native tests and CI pass.
- [ ] Startup, serial protocol, queued sorting, homing, and default hardware
      behavior pass regression checks.
- [ ] Stop and recovery pass bench tests at every documented interruption
      point.
- [ ] AirDrop and PWM variants are tested when their code paths changed.
- [x] Firmware/application compatibility boundaries and intentional protocol changes
      are documented in release notes.

## Dependency order

1. Record the baseline.
2. Land isolated fixes.
3. Add optional native tests and Uno CI compilation.
4. Replace serial reception and parsing.
5. Implement explicit stop and recovery semantics.
6. Convert blocking waits incrementally.
7. Correct diagnostic slot configuration.
8. Update documentation and perform the release regression matrix.

Do not start with a wholesale PlatformIO migration or a single large
state-machine rewrite. The plan is deliberately sequenced so each risky change
has a known baseline, focused tests, and a reversible review boundary.

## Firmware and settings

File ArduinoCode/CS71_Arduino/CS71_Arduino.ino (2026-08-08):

/// VERSION CS 7.1.260714.6 ///
/// REQUIRES AI SORTER SOFTWARE VERSION 1.1.46 or newer

#include <Wire.h>
#include <SoftwareSerial.h>
#include <string.h>
#include "command_parser.h"
#include "feed_completion.h"
#include "fault_state_tracker.h"
#include "logic.h"
#include "machine_state.h"
#include "physical_request_tracker.h"
#include "protocol.h"
#include "proximity_settler.h"
#include "runtime_timer.h"
#include "step_sequence.h"

#define FIRMWARE_VERSION CS71_FIRMWARE_VERSION

//PIN CONFIGURATIONS
//ARDUINO UNO WITH 4 MOTOR CONTROLLER
//Stepper controller is set to 16 Microsteps (3 jumpers in place)

#define UseArduinoPWMDimmer false //if you have configured your hardware for to use arduino PWM dimmer for light control, set this to true. See: https://github.com/sjseth/AI-Case-Sorter-CS7.1/tree/main/CommunityContributions/ArduinoCode/ausrobbo/LED%20Control

#if UseArduinoPWMDimmer == false 
  #define FEED_SENSOR 9 //the proximity sensor under the feed wheel 
  #define CAMERA_LED_PWM 13 //NOT USED
#else
  #define FEED_SENSOR 13 //the proximity sensor under the feed wheel 
  #define CAMERA_LED_PWM 9 //the output pin for the digital PWM 
#endif

#define CAMERA_LED_LEVEL  78 //camera brightness if using digital PWM, otherwise ignored 


#define FEED_DIRPIN 5 //maps to the DIRECTION signal for the feed motor
#define FEED_STEPPIN 2 //maps to the PULSE signal for the feed motor

#define FEED_MICROSTEPS 16  //how many microsteps the controller is configured for. 
#define FEED_HOMING_SENSOR 10  //connects to the feed wheel homing sensor
#define FEED_HOMING_SENSOR_TYPE 1 //1=NO (normally open) default switch, 0=NC (normally closed) (optical switches) 
#define FEEDSENSOR_ENABLED true //enabled if feedsensor is installed and working;//this is a proximity sensor under the feed tube which tells us a case has dropped completely
#define FEEDSENSOR_TYPE 0 // NPN = 0, PNP = 1
#define FEED_DONE_SIGNAL 12   // Writes HIGH Signal When Feed is done. Used for mods like AirDrop
#define FEED_HOMING_ENABLED true //enabled feed homing sensor

#define SORT_DIRPIN 6 //maps to the DIRECTION signal for the sorter motor
#define SORT_STEPPIN 3 //maps to the PULSE signal for the sorter motor

#define SORT_MICROSTEPS 16 //how many microsteps the controller is configured for. 
#define SORT_HOMING_SENSOR 11  //connects to the sorter homing sensor
#define SORT_HOMING_SENSOR_TYPE 1 //1=NO (default) normally open, 0=NC (normally closed) (optical switches) 
#define SORT_HOMING_OFFSET_STEPS 0 //additional steps to continue after homing sensor triggered
#define SORT_FULL_REVOLUTION_STEPS 200
#define SORT_HOMING_MARGIN_STEPS 10 //allows for a sensor offset beyond one nominal revolution

#define AIR_DROP_ENABLED false //enables airdrop

#define MOTOR_Enable 8 //maps to the enable pin for the FEED MOTOR (on r3 shield enable is shared by motors)
#define AUTO_MOTORSTANDBY_TIMEOUT 60 // 0 = disabled; The time in seconds to wait after no motor movement before putting motors in standby
static_assert(AUTO_MOTORSTANDBY_TIMEOUT >= 0, "Motor standby timeout cannot be negative");
static_assert(AUTO_MOTORSTANDBY_TIMEOUT <= MAX_STANDBY_TIMEOUT_SECONDS,
              "Motor standby timeout is too large");
//ARDUINO CONFIGURATIONS

//number of steps between chutes. With the 8 and 10 slot attachments, 20 is the default. 
//If you have customized sorter output drops, you will need to change this setting to meet your needs. 
//Note there are 200 steps in 1 revolution of the sorter motor. 
#define SORTER_CHUTE_SEPERATION 20 
// Number of slots exercised by test: and sorttest:. This is independent of
// SORTER_CHUTE_SEPERATION and may also be changed at runtime with slotcount:.
#define SORTER_SLOT_COUNT 8
static_assert(
    isSlotCountRepresentable(SORTER_SLOT_COUNT, SORTER_CHUTE_SEPERATION,
                             SORT_MICROSTEPS),
    "Highest diagnostic slot exceeds AVR int movement range");


#define FEED_HOMING_OFFSET_STEPS 3 //additional steps to continue after homing sensor triggered
#define FEED_STEPS 70  //The amount to travel before starting the homing cycle. Should be less than (80 - FEED_HOMING_OFFSET_STEPS)
#define FEED_OVERSTEP_THRESHOLD 90 //if we have gone this many steps without hitting a homing node, something is wrong. Throw an overstep error

//FEED MOTOR ACCELLERATION SETTINGS (DISABLED BY DEFAULT)
#define FEED_ACC_SLOPE 32  //2 steps * 16 MicroStes

#define FEED_MOTOR_SPEED 90 //range of 1-100
#define ACC_FEED_ENABLED false //enabled or disables feed motor accelleration. 

//SORT MOTOR ACCELLERATION SETTINGS (ENABLED BY DEFAULT)
#define ACC_SORT_ENABLED true
#define SORT_MOTOR_SPEED 90 //range of 1-100
#define SORT_ACC_SLOPE 64 //64 is default - slope this is the number of microsteps to accelerate and deaccellerate in a sort. 
#define ACC_FACTOR 1200 //1200 is default factor
#define SORT_HOMING_ENABLED true
//FEED DELAY SETTINGS

// Used to send signal to add-ons when feed cycle completes (used by airdrop mod). 
// IF NOT USING MODS, SET TO 0. With Airdrop set to 60-100 (length of the airblast)
#define FEED_CYCLE_COMPLETE_SIGNALTIME 50 

// The amount of time to wait after the feed completes before sending the FEED_CYCLE_COMPLETE SIGNAL
// IF NOT USING MODS, SET TO 0. with Airdrop set to 30-50 which allows the brass to start falling before sending the blast of air. 
#define FEED_CYCLE_COMPLETE_PRESIGNALDELAY 30

// Time in milliseconds to wait before sending "done" response to serialport (allows for everything to stop moving before taking the picture): runs after the feed_cycle_complete signal
// With AirDrop mod enabled, it needs about 20-30MS. If airdrop is not enabled, it should be closer to 50-70. 
// If you are getting blurred pictures, increase this value. 
#define FEED_CYCLE_NOTIFICATION_DELAY 90 

//when airdrop is enabled, this value is used instead of SLOT_DROP_DELAY but does the same thing
//Usually can be 100 or lower, increase value if brass not clearing the tube before it moves to next slot. 
#define FEED_CYCLE_COMPLETE_POSTDELAY 0

// number of MS to wait after feedcycle before moving sort arm.
// Prevents slinging brass. 
// This gives time for the brass to clear the sort tube before moving the sort arm. 
#define SLOT_DROP_DELAY 400

//DEBOUNCE is a feature to counteract case bounce which can occur if the machine runs out of brass and a peice of brass drops a distance from
//from the collator to the feeder. It developes speed and bounces of the prox sensor triggering the sensor and bouncing back up to cause a jam. 
//this requires the sensor to remain continuously active while the case settles.

#define DEBOUNCE_TIMEOUT 300 //default 500. The number of milliseconds without sensor activation (meaning no brass in the feed) required to trigger a debounce pause.

#define DEBOUNCE_PAUSE_TIME 500 //default 500. Set to 0 to disable. The number of milliseconds the sensor must remain continuously active.


///END OF USER CONFIGURATIONS ///
///DO NOT EDIT BELOW THIS LINE ///
Configuration configuration = {
    FEED_MOTOR_SPEED,
    FEED_STEPS,
    SORT_MOTOR_SPEED,
    SORTER_CHUTE_SEPERATION,
    SORTER_SLOT_COUNT,
    FEED_CYCLE_NOTIFICATION_DELAY,
    SLOT_DROP_DELAY,
    AIR_DROP_ENABLED,
    FEED_CYCLE_COMPLETE_POSTDELAY,
    FEED_CYCLE_COMPLETE_PRESIGNALDELAY,
    FEED_CYCLE_COMPLETE_SIGNALTIME,
    FEED_HOMING_OFFSET_STEPS,
    SORT_HOMING_OFFSET_STEPS,
    AUTO_MOTORSTANDBY_TIMEOUT,
    DEBOUNCE_TIMEOUT,
    DEBOUNCE_PAUSE_TIME,
    CAMERA_LED_LEVEL};

#define cameraLEDLevel configuration.cameraLedLevel
#define notificationDelay configuration.notificationDelay
#define airDropEnabled configuration.airDropEnabled
#define feedCycleSignalTime configuration.airDropSignalTime
#define feedCyclePreDelay configuration.airDropPreDelay
#define feedCyclePostDelay configuration.airDropPostDelay
#define slotDropDelay configuration.slotDropDelay
#define autoMotorStandbyTimeout configuration.autoMotorStandbyTimeout
#define feedSpeed configuration.feedSpeed
#define feedSteps configuration.feedSteps
#define sortSpeed configuration.sortSpeed
#define sortSteps configuration.sortSteps
#define slotCount configuration.slotCount
#define feedOffsetSteps configuration.feedHomingOffset
#define sortOffsetSteps configuration.sortHomingOffset
#define triggerTimeout configuration.debounceTimeout
#define debounceTime configuration.debouncePauseTime

int dropDelay =  airDropEnabled ? feedCyclePostDelay : slotDropDelay;

uint32_t autoMotorStandbyTimeoutMs = AUTO_MOTORSTANDBY_TIMEOUT * 1000UL;

int feedMotorSpeed = 500;//this is default and calculated at runtime. do not change this value

int sortMotorSpeed = 500;//this is default and calculated at runtime. do not change this value
int homingSteps = 0;

int feedMicroSteps = feedSteps * FEED_MICROSTEPS;

const int feedramp = (ACC_FACTOR + (FEED_MOTOR_SPEED /2)) / FEED_ACC_SLOPE;
const int sortramp = (ACC_FACTOR + (SORT_MOTOR_SPEED /2)) / SORT_ACC_SLOPE;
int feedOverTravelSteps = feedMicroSteps - (FEED_OVERSTEP_THRESHOLD * FEED_MICROSTEPS);
int feedHomingOffset = feedOffsetSteps * FEED_MICROSTEPS;

bool FeedScheduled = false;
bool IsFeeding = false;
bool IsFeedHoming = false;
bool IsFeedHomingOffset = false;
bool FeedCycleInProgress = false;
bool FeedCycleComplete = false;
bool IsFeedError = false;
int FeedSteps = feedMicroSteps;
int FeedHomingOffsetSteps = feedHomingOffset;
int feedDelayMS = 150;
int sortDelayMS = 400;

bool forceFeed=false;
CommandParser commandParser;
FeedCompletion feedCompletion;
MachineState machineState;
ProtocolSession protocolSession;
FaultStateTracker faultStateTracker;
PhysicalRequestTracker physicalRequestTracker;
RawStopLineDetector rawStopLineDetector;
PendingCommand pendingCommand;
ProximitySettler proximitySettler;
int qPos1 = 0;
int qPos2 = 0;
int sortStepsToNextPosition = 0;
int sortStepsToNextPositionTracker=0;
bool SortInProgress = false;
bool SortComplete = false;
bool IsSorting = false;
int sortHomingOffset = sortOffsetSteps * SORT_MICROSTEPS;
bool IsSortHoming = false;
bool IsSortHomingOffset = false;
int SortHomingOffsetSteps = sortHomingOffset;
RuntimeTimer slotDropGate;
int pendingQueuedDestination = 0;
StepSequence sorterJog;
bool sorterJogStartsFeedHoming = false;

bool IsTestCycle=false;
bool IsSortTestCycle=false;
RuntimeTimer sortTestPacing;
const uint32_t SORT_TEST_PACING_MS = 40;
int testCycleInterval=0;
int testsCompleted=0;
int sortToSlot=0;
unsigned long theTime;
unsigned long timeSinceLastSortMove;
unsigned long timeSinceLastMotorMove;
unsigned long msgResetTimer;

bool proxActivated = false;
bool motorDriversEnabled = false;
uint32_t configGeneration = 0;
const uint32_t V2_CONFIG_GENERATION_MAX = 999999999UL;

#if PROTOCOL_V2_ENABLED
void baselineV2State();
void emitV2StateIfChanged();
void serviceV2PhysicalRequest();
void finishV2PhysicalRequest(uint16_t requestId,
                             PhysicalRequestOperation operation, int slot);
#endif
void applyV1Action(const V1DispatchResult &result);

void advanceConfigGeneration() {
  configGeneration = configGeneration == V2_CONFIG_GENERATION_MAX
                         ? 0
                         : configGeneration + 1UL;
}

void setMotorDriversEnabled(bool enabled) {
  motorDriversEnabled = enabled;
  digitalWrite(MOTOR_Enable, enabled ? LOW : HIGH);
}

void emitV1Response(void *, V1Response response) {
  switch (response) {
#define CS71_EMIT_V1_RESPONSE(name, text) \
  case V1Response::name:                  \
    Serial.print(F(text));                 \
    return;
    CS71_V1_RESPONSE_LIST(CS71_EMIT_V1_RESPONSE)
#undef CS71_EMIT_V1_RESPONSE
  }
}

ResponseSink responseSink = {0, emitV1Response};

void emitV1ConfigurationText(void *, V1ConfigurationText text) {
  switch (text) {
#define CS71_EMIT_V1_CONFIGURATION_TEXT(name, value) \
  case V1ConfigurationText::name:                    \
    Serial.print(F(value));                           \
    return;
    CS71_V1_CONFIGURATION_TEXT_LIST(CS71_EMIT_V1_CONFIGURATION_TEXT)
#undef CS71_EMIT_V1_CONFIGURATION_TEXT
  }
}

void emitV1Unsigned(void *, uint32_t value) {
  Serial.print(value);
}

void emitV1Version(void *) {
  Serial.print(F(FIRMWARE_VERSION));
  Serial.print(F("\n"));
}

V1OutputWriter v1OutputWriter = {
    0, emitV1Response, emitV1ConfigurationText, emitV1Unsigned, emitV1Version};
V1DispatchLimits v1DispatchLimits = {
    MAX_AVR_INT, MAX_STANDBY_TIMEOUT_SECONDS, SORT_FULL_REVOLUTION_STEPS,
    SORT_MICROSTEPS};

bool executionBusy() {
  return FeedScheduled || IsFeeding || IsFeedHoming || IsFeedHomingOffset ||
         FeedCycleInProgress || (FeedCycleComplete && !IsFeedError) ||
         feedCompletion.isActive() || SortInProgress || slotDropGate.isActive() ||
         IsSorting || IsSortHoming || IsSortHomingOffset ||
         sorterJog.isActive() || IsTestCycle || IsSortTestCycle;
}

void clearPendingCommand() {
  pendingCommand.clear();
}

void updateRecoveryCompletion(MachineAxis axis) {
  if (!machineState.axis(axis).recoveryInProgress) {
    return;
  }

  if (machineState.completeRecovery(axis) &&
      machineState.queueResetRequired()) {
    qPos1 = 0;
    qPos2 = 0;
    machineState.acknowledgeQueueReset();
  }
}
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
void loop() {
   checkSerial();
   getProxState();
   const uint32_t now = millis();
   updateSlotDropGate(now);
   runSortMotor();
   onSortComplete();
   scheduleRun();
   checkFeedErrors();
   runFeedMotor();
   homeFeedMotor();
   homeSortMotor();
   serviceSorterJog();
   onFeedComplete(now);
   runAux();
   MotorStandByCheck();
#if PROTOCOL_V2_ENABLED
   serviceV2PhysicalRequest();
   emitV2StateIfChanged();
#endif
}

int FreeMem(){
  extern int __heap_start, *__brkval;
  int v;
  return(int) &v - (__brkval ==0 ? (int) &__heap_start : (int) __brkval);
}

void applyV1Action(const V1DispatchResult &result) {
  switch (result.action) {
    case V1Action::Stop:
      enterStoppedState();
      return;
    case V1Action::HomeFeeder:
      setMotorDriversEnabled(true);
      machineState.beginRecovery(MachineAxis::Feeder);
      feedDelayMS = 400;
      FeedSteps = feedMicroSteps;
      FeedHomingOffsetSteps = 0;
      FeedCycleInProgress = false;
      FeedCycleComplete = false;
      IsFeeding = false;
      IsFeedHomingOffset = false;
      IsFeedHoming = true;
      return;
    case V1Action::HomeSorter:
      setMotorDriversEnabled(true);
      machineState.beginRecovery(MachineAxis::Sorter);
      sortDelayMS = 400;
      SortComplete = false;
      IsSorting = false;
      IsSortHomingOffset = false;
      SortHomingOffsetSteps = 0;
      homingSteps = 0;
      IsSortHoming = false;
      jogSorter(false);
      return;
    case V1Action::QueueFeed:
    case V1Action::QueueForcedFeed:
      forceFeed = result.action == V1Action::QueueForcedFeed;
      moveSorterToNextPosition(result.value);
      FeedScheduled = true;
      IsFeeding = false;
      scheduleRun();
      return;
    case V1Action::SortTo:
      moveSorterToPosition(result.value);
      return;
    case V1Action::StartTest:
      IsTestCycle = true;
      testCycleInterval = result.value;
      testsCompleted = 0;
      FeedScheduled = false;
      FeedCycleInProgress = false;
      return;
    case V1Action::StartSortTest:
      IsSortTestCycle = true;
      sortTestPacing.cancel();
      testCycleInterval = result.value;
      testsCompleted = 0;
      return;
    case V1Action::ApplyFeedSpeed:
      setFeedMotorSpeed(feedSpeed);
      return;
    case V1Action::ApplySortSpeed:
      setSorterMotorSpeed(sortSpeed);
      return;
    case V1Action::ApplyFeedHomingOffset:
      feedHomingOffset = feedOffsetSteps * FEED_MICROSTEPS;
      FeedHomingOffsetSteps = feedHomingOffset;
      return;
    case V1Action::ApplySortHomingOffset:
      sortHomingOffset = sortOffsetSteps * SORT_MICROSTEPS;
      SortHomingOffsetSteps = sortHomingOffset;
      return;
    case V1Action::ApplyFeedSteps:
      feedMicroSteps = feedSteps * FEED_MICROSTEPS;
      feedOverTravelSteps =
          feedMicroSteps - (FEED_OVERSTEP_THRESHOLD * FEED_MICROSTEPS);
      return;
    case V1Action::ApplyDropDelay:
      dropDelay = airDropEnabled ? feedCyclePostDelay : slotDropDelay;
      return;
    case V1Action::ApplyAutoMotorStandbyTimeout:
      autoMotorStandbyTimeoutMs = autoMotorStandbyTimeout * 1000UL;
      return;
    case V1Action::ApplyCameraLedLevel:
      adjustCameraLED(result.value);
      return;
    default:
      return;
  }
}

void handleV1Frame(V1FrameStatus status, const char *command, size_t length,
                   bool dispatchingPending = false) {
#if PROTOCOL_V2_ENABLED
  if (!dispatchingPending && status == V1FrameStatus::Ready) {
    const V2NegotiationAction negotiation = dispatchV2Negotiation(
        command, length, executionBusy(), pendingCommand.available());
    if (negotiation == V2NegotiationAction::Busy) {
      responseSink.v1(V1Response::Busy);
      return;
    }
    if (negotiation == V2NegotiationAction::Discovery) {
      Serial.print(F("protocol:2 available\n"));
      return;
    }
    if (negotiation == V2NegotiationAction::Activate) {
      Serial.print(F("protocol:2 ready\n"));
      Serial.flush();
      commandParser.reset();
      clearPendingCommand();
      protocolSession.enterV2();
      baselineV2State();
      return;
    }
  }
#endif
  V1DispatchContext context = {
      machineState.isRunning(), executionBusy(),
      pendingCommand.available() && !dispatchingPending, qPos1, qPos2};
  V1DispatchResult result = dispatchV1Frame(
      status, command, length, context, &configuration, v1DispatchLimits);
  if (result.action == V1Action::QueuePending) {
    if (!pendingCommand.enqueue(command, length)) {
      responseSink.v1(V1Response::Busy);
    }
    return;
  }
  if (status == V1FrameStatus::Ready &&
      v1CommandIsSetter(classifyV1Command(command)) &&
      result.output == V1Output::Response &&
      result.response == V1Response::Ok) {
    advanceConfigGeneration();
  }
  applyV1Action(result);
  writeV1Output(result, configuration, UseArduinoPWMDimmer == true,
                v1OutputWriter);
}

void dispatchCommand(const char *command) {
  handleV1Frame(V1FrameStatus::Ready, command, strlen(command));
}

#if PROTOCOL_V2_ENABLED
bool isExactV2(const char *text, size_t length,
               const __FlashStringHelper *expected) {
  const char *flashText = reinterpret_cast<const char *>(expected);
  return text != 0 && strlen_P(flashText) == length &&
         memcmp_P(text, flashText, length) == 0;
}

void beginV2Line(uint16_t requestId, const __FlashStringHelper *prefix) {
  Serial.write('@');
  Serial.print(requestId);
  Serial.write(' ');
  Serial.print(prefix);
}

void finishV2Line() {
  Serial.write('\n');
}

void emitV2DataUnsigned(uint16_t requestId, const __FlashStringHelper *key,
                        uint32_t value) {
  beginV2Line(requestId, F("data:"));
  Serial.print(key);
  Serial.print(value);
  finishV2Line();
}

void emitV2DataText(uint16_t requestId, const __FlashStringHelper *key,
                    const __FlashStringHelper *value) {
  beginV2Line(requestId, F("data:"));
  Serial.print(key);
  Serial.print(value);
  finishV2Line();
}

bool emitV2Terminal(V2RequestLifecycle *lifecycle, uint16_t requestId,
                    bool error, const __FlashStringHelper *detail = 0) {
  if (lifecycle == 0 || !lifecycle->owns(requestId)) return false;
  beginV2Line(requestId, error ? F("error:") : F("done"));
  if (detail != 0) {
    if (!error) Serial.write(':');
    Serial.print(detail);
  }
  finishV2Line();
  return lifecycle->terminal(requestId);
}

void emitV2Event(const __FlashStringHelper *detail) {
  Serial.write('!');
  Serial.print(protocolSession.nextEventSequence());
  Serial.write(' ');
  Serial.print(detail);
  finishV2Line();
}

V2MachineActivity currentV2MachineActivity() {
  const V2MachineActivity activity = {
      FeedScheduled, IsFeeding, IsFeedHoming, IsFeedHomingOffset,
      feedCompletion.isActive(), feedCompletion.airDropActive(),
      SortInProgress || IsSorting, IsSortHoming, IsSortHomingOffset,
      sorterJog.isActive(), slotDropGate.isActive(), FeedCycleInProgress,
      FeedCycleComplete, IsFeedError, IsTestCycle || IsSortTestCycle};
  return activity;
}

void emitV2Mode(MachineMode mode) {
  switch (mode) {
    case MachineMode::Running: Serial.print(F("running")); return;
    case MachineMode::Recovering: Serial.print(F("recovering")); return;
    case MachineMode::Stopped: Serial.print(F("stopped")); return;
  }
}

void emitV2PhaseName(MachinePhase phase) {
  switch (phase) {
    case MachinePhase::FeedWait: Serial.print(F("feed_wait")); return;
    case MachinePhase::FeedMove: Serial.print(F("feed_move")); return;
    case MachinePhase::FeedHome: Serial.print(F("feed_home")); return;
    case MachinePhase::SortMove: Serial.print(F("sort_move")); return;
    case MachinePhase::SortHome: Serial.print(F("sort_home")); return;
    case MachinePhase::Settling: Serial.print(F("settling")); return;
    case MachinePhase::AirDrop: Serial.print(F("airdrop")); return;
    case MachinePhase::Diagnostic: Serial.print(F("diagnostic")); return;
    case MachinePhase::Idle: Serial.print(F("idle")); return;
  }
}

void baselineV2State() {
  const MachinePhase phase = deriveMachinePhase(currentV2MachineActivity());
  faultStateTracker.baseline(static_cast<uint8_t>(machineState.mode()),
                             static_cast<uint8_t>(phase));
}

void emitV2StateIfChanged() {
  if (protocolSession.mode() != ProtocolMode::V2) return;
  const MachinePhase phase = deriveMachinePhase(currentV2MachineActivity());
  if (!faultStateTracker.observeState(static_cast<uint8_t>(machineState.mode()),
                                      static_cast<uint8_t>(phase)))
    return;
  Serial.write('!');
  Serial.print(protocolSession.nextEventSequence());
  Serial.print(F(" state:mode="));
  emitV2Mode(machineState.mode());
  Serial.print(F(" phase="));
  emitV2PhaseName(phase);
  finishV2Line();
}
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

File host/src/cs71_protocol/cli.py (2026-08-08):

"""The safe CS7.1 v1/v2 compatibility switcher command."""

from __future__ import annotations

import argparse
import json
import math
import subprocess
import sys
from collections.abc import Callable, Sequence
from contextlib import contextmanager
from dataclasses import dataclass
from typing import Any, Protocol

from .client import ProtocolClient
from .errors import DtrSuppressionError, ProtocolError, RecoveryError, TimeoutError
from .locking import PortLock, PortLockError
from .models import SessionMode
from .transport import SerialTransport

EXIT_SUCCESS = 0
EXIT_USAGE = 2
EXIT_PORT_UNAVAILABLE = 3
EXIT_PROTOCOL = 4
EXIT_RECOVERY = 5
EXIT_DTR_GUARANTEE = 6
EXIT_CHILD_LAUNCH = 7


class DtrGuaranteeError(RuntimeError):
    """Opening the port could have reset the controller before a safe stop."""


class SafetyGuaranteeError(RuntimeError):
    """The requested operation cannot establish its required safety barrier."""


class UsageError(ValueError):
    """An argparse usage error rendered by ``main`` in the selected format."""


class _ArgumentParser(argparse.ArgumentParser):
    def error(self, message: str) -> None:
        raise UsageError(message)


class Lock(Protocol):
    def acquire(self) -> None: ...
    def release(self) -> None: ...


@dataclass
class Dependencies:
    opener: Callable[..., Any] = SerialTransport.open
    lock_factory: Callable[[str], Lock] = PortLock
    runner: Callable[[Sequence[str]], Any] = lambda argv: subprocess.run(argv, check=False)


def _close(transport: Any) -> None:
    close = getattr(transport, "close", None)
    if callable(close):
        close()


@contextmanager
def _session(port: str, timeout: float, dependencies: Dependencies):
    lock = dependencies.lock_factory(port)
    transport: Any | None = None
    lock.acquire()
    try:
        transport = dependencies.opener(port, baudrate=9600, timeout=min(timeout, 0.05))
        if not getattr(transport, "dtr_suppression_guaranteed", False):
            raise DtrGuaranteeError(
                "could not guarantee DTR suppression while opening the port; no safe stop was sent"
            )
        yield transport
    finally:
        try:
            if transport is not None:
                _close(transport)
        finally:
            lock.release()


def _reset_and_verify_v1(client: ProtocolClient, transport: Any) -> None:
    """Apply the normative stop/reset/Ready/ping barrier."""
    client.out_of_band_stop()
    try:
        transport.reset()
        client.reader.clear()
        client.wait_ready()
        client.v1_ping_barrier()
    except RecoveryError as exc:
        if exc.recovered:
            raise
        raise RecoveryError(
            "reset did not verify a v1 session", recovered=False
        ) from exc
    except Exception as exc:
        raise RecoveryError(
            "reset did not verify a v1 session", recovered=False
        ) from exc


def _detect(client: ProtocolClient, transport: Any) -> dict[str, Any]:
    _reset_and_verify_v1(client, transport)
    client._write_v1("version")
    version = client._read_v1()
    available = client.discover()
    return {
        "v2_available": available,
        "firmware": "v2-capable" if available else "v1-only",
        "mode": "v1",
        "version": version,
        "reset": True,
    }


def _prepare(port: str, timeout: float, dependencies: Dependencies) -> dict[str, Any]:
    with _session(port, timeout, dependencies) as transport:
        client = ProtocolClient(transport, timeout=timeout, reset=transport.reset)
        _reset_and_verify_v1(client, transport)
        return {"mode": "v1", "volatile_settings_reset": True}


def execute(args: argparse.Namespace, dependencies: Dependencies | None = None) -> tuple[int, dict[str, Any]]:
    """Execute a parsed command; injectable dependencies keep tests hardware-free."""
    dependencies = dependencies or Dependencies()
    try:
        if not math.isfinite(args.timeout) or args.timeout <= 0:
            return EXIT_USAGE, {"error": "--timeout must be finite and greater than zero"}
        if args.command in {"detect", "enter-v2"} and getattr(args, "no_reset", False):
            raise SafetyGuaranteeError(
                "--no-reset cannot verify v1 after universal stop; use the required reset barrier"
            )
        if args.command == "prepare-legacy":
            return EXIT_SUCCESS, _prepare(args.port, args.timeout, dependencies)
        if args.command == "run-legacy":
            _prepare(args.port, args.timeout, dependencies)
            application = args.application[1:] if args.application[:1] == ["--"] else []
            if not application:
                return EXIT_USAGE, {"error": "run-legacy requires an application after --"}
            try:
                child = dependencies.runner(application)
            except OSError as exc:
                return EXIT_CHILD_LAUNCH, {"error": str(exc), "prepared": True}
            return int(child.returncode), {"prepared": True, "child_exit": int(child.returncode)}

        with _session(args.port, args.timeout, dependencies) as transport:
            client = ProtocolClient(transport, timeout=args.timeout, reset=transport.reset)
            if args.command == "detect":
                return EXIT_SUCCESS, _detect(client, transport)
            if args.command == "enter-v2":
                result = _detect(client, transport)
                if not result["v2_available"]:
                    return EXIT_SUCCESS, result
                client.activate_known_available()
                if args.crc:
                    client.enable_crc()
                return EXIT_SUCCESS, {
                    **result, "mode": client.mode.value, "crc": client.crc_enabled,
                    "validated": ["protocolversion", "capabilities", "status"],
                }
            if args.command == "leave-v2":
                # A CLI invocation starts without a trustworthy v2 session.  Do
                # not guess framing or CRC: force the universal v1 recovery path.
                _reset_and_verify_v1(client, transport)
                return EXIT_SUCCESS, {"mode": SessionMode.V1.value, "method": "safe-stop-reset-fallback"}
        raise AssertionError("unknown command")
    except (DtrGuaranteeError, DtrSuppressionError) as exc:
        return EXIT_DTR_GUARANTEE, {"error": str(exc), "dtr_suppression_guaranteed": False}
    except SafetyGuaranteeError as exc:
        return EXIT_DTR_GUARANTEE, {"error": str(exc), "safety_guarantee": False}
    except (PortLockError, OSError, RuntimeError) as exc:
        return EXIT_PORT_UNAVAILABLE, {"error": str(exc)}
    except RecoveryError as exc:
        if exc.recovered:
            return EXIT_PROTOCOL, {"error": str(exc), "mode": "v1", "recovered": True}
        return EXIT_RECOVERY, {"error": str(exc), "mode": "uncertain"}
    except (TimeoutError, ProtocolError) as exc:
        return EXIT_PROTOCOL, {"error": str(exc)}
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

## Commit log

2026-03-16 Added silverbullit mods
    [BF556 300 - ElectronicBoxModBLUEforgotsizexsizeHorisontal_BoxV2.stl, BF556 300 - ElectronicBoxModRED52x72Vertical_BoxV2.stl, BF556 300 - ElectronicBoxModRED52x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]
2026-07-15 Fix firmware bounds and timeout handling
    [CS71_Arduino.ino, test_main.cpp]
2026-07-15 Replace serial input with a bounded parser
    [CS71_Arduino.ino, test_main.cpp]
2026-07-15 Make sorter drop clearance nonblocking
    [CS71_Arduino.ino, test_main.cpp]
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2026-08-06 Route v2 configuration through shared handlers
    [uno-v2-configuration-resource.txt]
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2026-08-11 test(appliance): add adverse simulator fixtures
    [transport.py]
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2026-08-11 feat(appliance): add sole serial worker and admission queues
    Implement PI-DAEMON-001. `cs71d.SerialWorker` owns one transport and one
    `ProtocolClient` on a dedicated thread and performs every read and write;
    callers submit closed typed intents and receive futures. The thin
    `protocol_boundary` re-export is replaced by this owning boundary.
    Admission uses a bounded normal lane that rejects with `QueueFullError`
    rather than allocating without limit, and a priority-stop lane admitted
    independently of normal-lane saturation. Exactly one state-changing
    operation is dispatched at a time.
    Preemption is fail-closed: work invalidated by a trusted stop fails with
    `PreemptedByStopError`, and a stop th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
2026-08-11 feat(appliance): publish session state and conservative reconnect
    Implement PI-DAEMON-002. `cs71d.SessionState` publishes the connection
    walk `DISCONNECTED -> CONNECTING -> VERIFYING_V1 -> ACTIVATING_V2 ->
    READY` with a monotonic snapshot generation, where every material
    transition increments the generation exactly once and re-entering a state
    is not material.
    Connection state is session confidence and stays separate from
    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
2026-08-11 docs: require explicit ways of working
    "Update documentation when behavior changes" was too vague to act on: a
    recent change synchronized roadmap.md, backlog.md and the READMEs but left
    issues.md describing two open tasks that had shipped, because the required
    file set was inferred from what an earlier commit happened to touch.
    Replace the inference with a table of files and the condition that obliges
    each one, and record the rest of the working requirements that were until
    now only conventions: verify library behavior before designing against it,
    await published transitions instead of sleeping in concurrency tests, state
    the evidence class, and the branch/PR/merge flow including why a docs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
2026-08-11 feat(appliance): add durable operation journal
    Implement the durable half of PI-DOMAIN-001: the operation model and the
    machine.db journal that records it. Admission against snapshot generation,
    idempotent replay and worker dispatch follow in the next change.
    cs71d.operations is pure vocabulary — UUID identity, restricted actor
    attribution, a finite deadline, the QUEUED → ACCEPTED → RUNNING → terminal
    lifecycle, and the canonical request fingerprint over action, body and actor.
    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
2026-08-11 feat(appliance): admit operations against snapshot generation
    Complete PI-DOMAIN-001. Admission now evaluates the idempotency key, the
    observed snapshot generation and machine readiness while holding the machine
    view still, and makes the operation durable before anything is enqueued, so a
    stale or duplicate request never reaches the controller.
    cs71d.MachineState owns the snapshot generation. It belongs to the machine
    rather than the serial session: SessionState folds connection confidence into
    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
2026-08-11 feat(appliance): fail closed on journal loss and priority stop
    Complete PI-DOMAIN-002.
    A refused journal write latches the machine view as undurable with a LATCHED
    fault. It stops admitting work and rejects new motion with JOURNAL_UNAVAILABLE,
    and it does not clear on its own: durability loss needs operator or service
    intervention, so the daemon stays not-ready rather than quietly resuming
    control on an unrecorded path.
    The dispatch gate added in PI-DOMAIN-001 does the load-bearing work here. A
    lifecycle write that cannot be recorded raises before the first byte, so the
    command never reaches the controller. A terminal that cannot be recorded leaves
    the operation non-successful; the daemon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
2026-08-11 feat(appliance): validate operations against advertised capabilities
    Complete PI-DOMAIN-003 for the operations the firmware actually implements.
    The serial worker now gathers the required snapshots — advertised capabilities
    and observed status — before publishing READY, and re-observes them after each
    completed movement. runtime-and-domain.md already required that READY means a
    verified session *and* that required snapshots exist; this makes that true.
    The daemon consequently validates commands against what the controller
    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
2026-08-11 feat(appliance): serve the private API on a Unix socket
    Deliver the read side of PI-API-001. The state-changing endpoints, the session
    and configuration resources, and the entry-point wiring follow.
    cs71d.api.ApiServer serves health, snapshot and operation resources over a Unix
    domain socket and nothing else. There is no TCP code path to misconfigure: no
    daemon module names an internet address family, and a static test keeps it that
    way rather than asserting it at runtime. The socket is created with
    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
2026-08-11 feat(appliance): serve the state-changing API commands
    Continue PI-API-001. `/v1/operations/home`, `/sort`, `/feed` and
    `/v1/machine/stop` are served over the same Unix socket, each requiring
    Idempotency-Key, If-Match-Generation and X-Deadline-Ms, and each returning
    202 OperationAccepted with the durable operation identity and its status URL.
    Only a priority stop accepts `*` for the observed generation, because a
    recovering or uncertain view is exactly when an operator needs it; every other
    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
2026-08-11 feat(appliance): run the assembled daemon from the entry point
    Complete the last software piece of PI-API-001 that has a domain behind it.
    `cs71d --serve` assembles the running daemon in dependency order — journal,
    then domain and serial worker, then the socket — and unwinds it in reverse, so
    no new request is admitted while the worker is still finishing the one it
    holds. SIGINT and SIGTERM request shutdown rather than forcing it.
    The service credential is read from a protected file named by the new
    service_token_path configuration field. It is never a configuration value or a
    command-line argument, because both are readable by any local user through the
    configuration file and the proce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
    [cli.py]
2026-08-12 feat(appliance): apply versioned daemon configuration
    Complete PI-DOMAIN-004 and, with it, PI-API-001.
    cs71d.configuration holds daemon policy: heartbeat interval, event and
    operation retention, and the maximum deadline the daemon will accept. These are
    the daemon's own settings. Applying a change moves no motor and never reaches
    the controller, which a test asserts by comparing the serial transcript across
    a change.
    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
2026-08-12 feat(appliance): stream bounded resumable daemon events
    Implement PI-API-002.
    cs71d.events.EventRing retains a bounded window of events and fans them out.
    Publishing never blocks: events are produced on the serial worker thread, the
    same thread that has to keep answering a priority stop, so a subscriber that
    stops reading is dropped rather than allowed to apply backpressure to the
    machine. A test publishes two hundred events against a stalled subscriber and
    asserts the publisher completes.
    Loss is always explicit. A subscriber that overruns its bounded queue, resumes
    from a cursor the ring no longer retains, or presents a cursor from a previous
    daemon life receives snapshot.required and mu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
2026-08-12 build(web): add and verify the authentication runtime dependencies
    Begin PI-WEB-001. The web workspace had no runtime dependencies at all, so
    choosing these is a supply-chain decision for an appliance rather than a
    detail, and it is recorded with its reasoning in the backlog.
    @node-rs/argon2 provides the Argon2id hashes. It ships prebuilt arm64 and x64
    binaries, so nothing compiles on the appliance. The common alternative needs a
    node-gyp toolchain on the device, and a pure-WASM hash is too slow to run
    honest parameters on a Pi.
    better-sqlite3 opens web.db. Its API is synchronous, which suits SSR request
    handling, and it is stable rather than experimental. Node's built-in
    node:sqlite would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
2026-08-12 feat(web): enforce the documented RBAC matrix server-side
    The RBAC matrix from docs/architecture/security-and-safety.md now has exactly
    one implementation. `capabilities.ts` transcribes it as data and routes ask for
    a capability rather than for a role, so the next change to the table is one edit
    instead of a search for every handler that compared a role name. Its spec
    asserts each role and capability pair against a hand-written copy of the
    documented table rather than against the implementation, and names the two rows
    that are easiest to get wrong: a viewer may stop the machine, and no role at all
    -- administrator included -- may drive the protocol or the device path.
    `policy.ts` declares w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
2026-08-12 feat(web): add the socket-only daemon client and command translation
    The web workspace can now speak to cs71d, and only in one way.
    appliance/web/src/lib/server/daemon/ exposes named commands with typed
    arguments; there is no host, no port and no URL anywhere in it. The socket path
    comes from configuration and every request path is a literal the client builds,
    so a browser has nothing to point somewhere else, and there is no method that
    takes a path, a device or a protocol string for it to reach through.
    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
2026-08-12 feat(web): command the machine from the dashboard, and record who asked
    The dashboard now reads the daemon's snapshot in its load and submits the
    software stop as a named action, which completes PI-BFF-001.
    Authorization happens in the action, next to the effect, rather than being
    inferred from the fact that a page rendered a button. A daemon that is not
    answering makes the page report that rather than fail: the screen is what an
    operator has when the machine has gone quiet, and the stop control has to stay
    on it.
    The stop never reuses an idempotency key. Deduplication is for a resubmitted
    intent; a second press of stop is a second intent, and a replayed key would let
    the daemon answer wit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
2026-08-12 fix(ops): StartLimit* belongs in [Unit], and /usr/bin/node on the CI runner
    StartLimitIntervalSec/StartLimitBurst under [Service] are silently ignored
    by systemd (a real placement bug, not just noise) - moved to [Unit] in both
    units, with a regression test.
    cs71-web.service's ExecStart hardcodes /usr/bin/node, matching how Node
    lands on a real Debian/Raspberry Pi OS install (e.g. via NodeSource) - but
    actions/setup-node installs into the runner's toolcache instead, so the
    smoke test's derived unit failed to exec (203/EXEC). Symlinking node to
    that path in the CI job matches production without pretending the runner
    did an apt install it did not.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
2026-08-12 fix(ops): wait for the socket file, not just service-active
    systemd reports Type=simple as active(running) the moment the process
    forks - not once it has actually opened its journal and bound the socket.
    Both derived units came up active in the previous run, but the socket check
    ran before cs71d had gotten that far. Poll for the socket file itself.
2026-08-12 fix(ops): give cs71-web real cs71-api group membership, not just systemd's grant
    cs71-web.service's SupplementaryGroups=cs71-api is systemd's own grant and
    needs no /etc/group entry to work when systemd starts the process - but the
    smoke test's cross-identity socket check runs via runuser, which only sees
    real OS-level group membership. curl failed to connect (exit 7) because
    cs71-web was never actually added to cs71-api. Add it in install.sh, in
    addition to (not instead of) the unit's own directive, so anything reaching
    this identity a different way - su, runuser, a technician's shell - sees
    the same access systemd would have granted it.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
2026-08-12 feat(appliance): implement PI-OPS-002 backup, upgrade and rollback
    Adds appliance/ops/backup.sh (SQLite-consistent, checksummed, manifest'd
    backup of both databases and configuration, no secrets, daily timer),
    restore.sh (manifest/integrity verification before touching anything live,
    then a validated daemon-then-web restart) and upgrade.sh (backup, rebuild
    from checkout, start daemon then web, roll artifacts and data back through
    restore.sh on any failure before the web service is confirmed healthy).
    Gives cs71d's production profile a DurabilityMonitor (storage_health.py)
    that latches new-work-blocking faults for low disk space or a stale/failed
    backup through the same mechanism a failed jo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
2026-08-12 feat(vision): implement PI-VISION-001, cs71-vision service skeleton
    Adds appliance/vision, a new Python workspace for the third appliance
    service (ADR-0013): a Camera capture abstraction (FixtureCamera,
    deterministic and dependency-free; V4L2Camera, opened through OpenCV's
    V4L2 backend rather than a hand-rolled ioctl implementation, since every
    small "V4L2 Python bindings" package on PyPI is GPL-licensed and this
    workspace is MIT, and no real V4L2 device exists anywhere in this
    environment to verify hand-written kernel-ABI struct layouts against), a
    threaded CaptureLoop that survives read/sink failures, and strict
    VisionConfig mirroring cs71d.config's three-profile/fixed-production-path
    shap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
    [cli.py]
2026-08-12 feat(vision): implement PI-VISION-002, self-labeled dataset correlation
    Adds cs71d's missing "which slot did a sort reach" evidence: terminal_fields
    is now an additive, optional field on the Operation contract, populated
    from the trusted terminal's own protocol fields (firmware already echoes
    done:slot=N; this was recorded in machine.db but never exposed via the
    API). A daemon test drives a real sort to a trusted terminal through the
    HTTP API and asserts the field is present.
    Adds cs71vision.daemon_client.DaemonClient, a minimal read-only Unix-socket
    HTTP client authenticated with its own service credential (a third copy of
    the shared secret, extending PI-OPS-001's two-file pattern to three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
    [cli.py]
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2026-08-13 feat(vision): confidence-gated hybrid autonomy for sort (PI-VISION-008)
    Lets a sufficiently confident classification submit an autonomous sort
    through the machine actor kind (PI-VISION-007), composing with the
    primer-presence gate (PI-VISION-010) that was built for exactly this.
    cs71vision.autonomy.may_autonomously_sort(suggestion, thresholds) is the
    composed gate, checked in a fixed order: primer first and unconditionally,
    then a per-class confidence threshold. A class absent from thresholds can
    never autonomously sort - conservative by omission, matching ADR-0013's
    "starting conservative... mostly manual" rather than a low default number.
    Since no trained primer detector exists yet, this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
    [cli.py]
2026-08-13 test(daemon,web): qualify contract, stress and failure behavior (PI-SWQ-001)
    Executes the software quality matrix testing-and-quality.md already
    specified as a target: property tests, concurrent-load stress tests,
    fault-injection verification, and an NFR-01/NFR-02 measurement harness -
    distinguishing genuine gaps from the substantial coverage ten prior
    epics already built, rather than duplicating it.
    Property tests (hypothesis, new dev dependency): fingerprint/
    canonicalization invariants (test_operations.py), stale-generation and
    idempotency-conflict rejection over generated inputs (test_domain.py),
    and the event ring's bounded-retention/resume-or-overflow behavior over
    generated retention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
2026-08-13 test(web): qualify security and accessibility controls (PI-SWQ-002)
    Same discipline as PI-SWQ-001: distinguish what nine prior epics already
    built from genuine gaps, and only add the latter.
    Authentication, session revocation, CSRF, rate limits and secret
    redaction were already thoroughly covered (sessions.spec.ts,
    passwords.spec.ts, csrf-flow.spec.ts, limits.ts/limits.spec.ts,
    command-flow.spec.ts's audit-redaction test) - cross-referenced, not
    duplicated. Socket exposure/service-permission verification was already
    recorded on generic Linux CI (smoke-test.sh, test_artifacts.py); no
    "staging" profile exists in code, so that language is resolved in the
    backlog write-up as meaning the product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
